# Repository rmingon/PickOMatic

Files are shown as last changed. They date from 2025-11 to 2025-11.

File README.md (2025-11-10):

# PickOMatic Motion Controller

Custom motion-control PCB for the PickOMatic pick-and-place toolchain. The board centers on an ATmega2560 (16 MHz) and exposes everything needed to drive the mechanics of a multi-head component placer: coordinated stepper motion, pneumatic handling, lighting, endstop monitoring, and USB connectivity for streaming G-code.

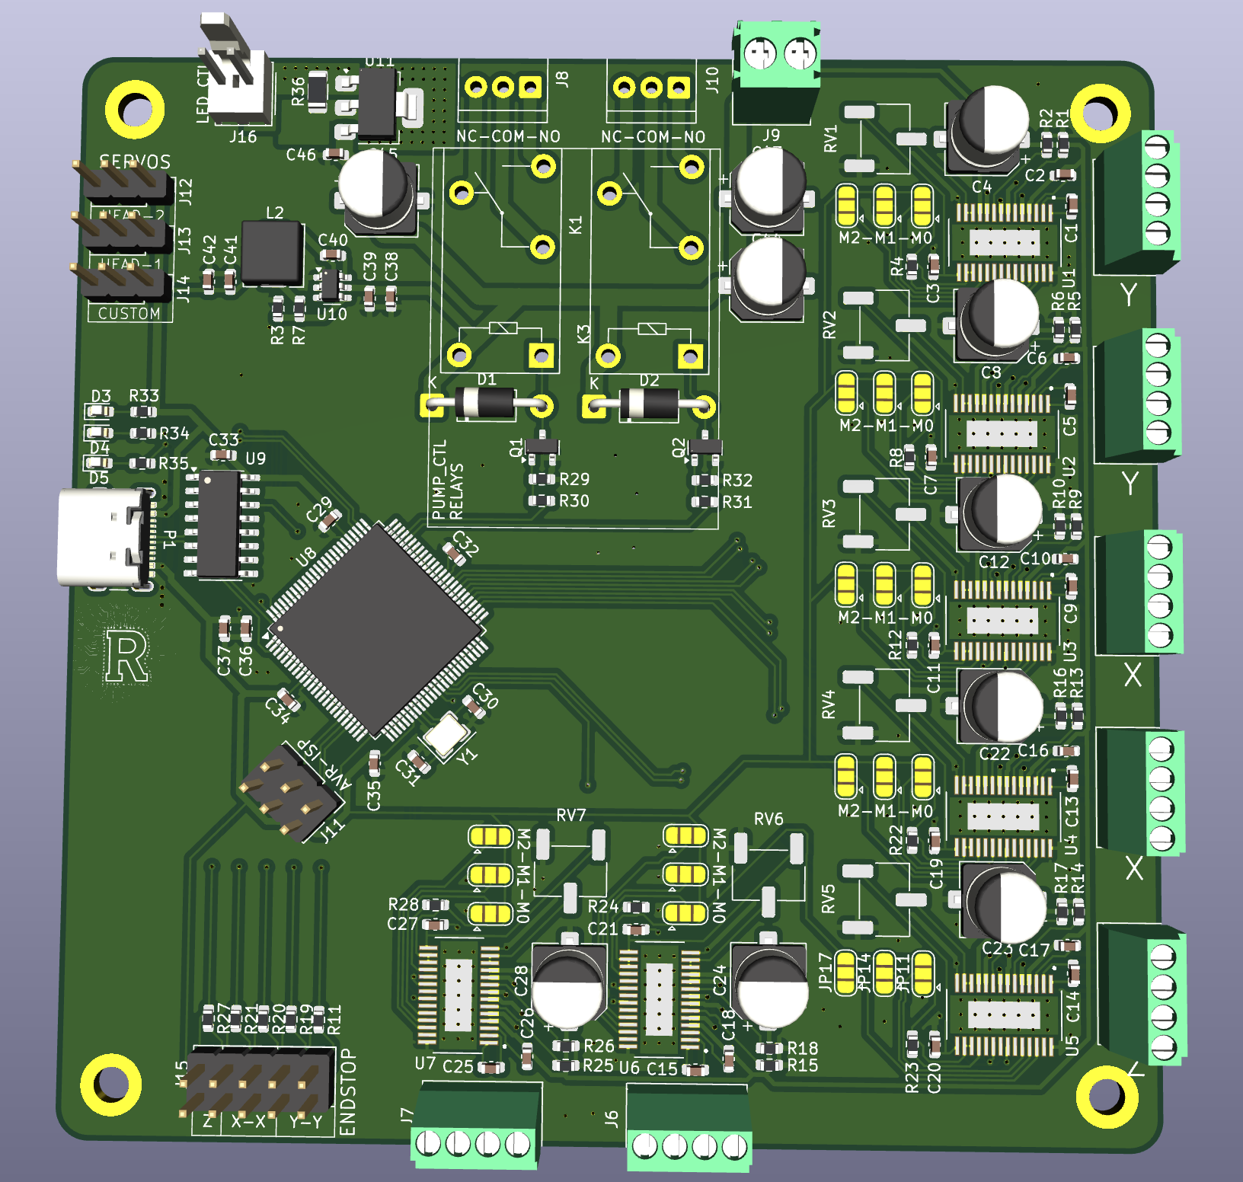
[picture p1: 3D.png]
3d


## Repository Layout

- `hardware/` – KiCad 8 project: schematic, PCB, fabrication outputs, and backups.
- `schematic.png` / `pcb.png` / `3D.png` – quick previews of the current design.

Open the KiCad project (`hardware/hardware.kicad_pro`) to inspect or modify the schematic/PCB.

## Hardware Highlights

| Function | Implementation |
| --- | --- |
| MCU | ATmega2560 @ 16 MHz with a full 5 V I/O bank exposed for motion, sensors, and auxiliary loads. |
| Programming | Standard 6-pin AVR-ISP header for bootloader bring-up, plus an onboard CH340C USB-UART for firmware uploads and runtime G-code/telemetry.  |
| Axis control | Five primary stepper channels (2×X, 2×Y, 1×Z) plus two auxiliary stepper channels dedicated to the dual picker heads. |
| Vertical compliance | Three hobby-servo outputs cooperate with the Z axis so each picker head can adjust nozzle height independently (fine pitch vs bulk parts). |
| Pneumatics & lighting | High-side driver for the vacuum/air pump and relay output for the inspection light that assists the vision camera. |
| Endstops | Five limit-switch inputs routed to PCINT lines so firmware can react immediately to any axis stop without polling latency. |

## Connectors & Loads

- **Power** – The digital domain remains at 5 V; provide the motor/lighting voltages required by your external drivers (consult the schematic to confirm connector pinouts and allowable current).
- **Steppers** – Eight pairs of STEP/DIR outputs let you interface with typical plug-in drivers (A4988, DRV8825, TMC series). Wire the two X and two Y channels to the corresponding gantry motors so firmware can keep them phase-aligned.
- **Servos** – Three 3-pin headers (signal/5 V/GND) drive standard RC servos for nozzle tilt or compliance adjustments.
- **Vacuum & light** – The pump driver is sized for continuous duty vacuum pumps; the relay contact can switch the illumination supply for the fiducial/alignment camera.
- **Endstops** – Use normally-closed switches whenever possible; the PCINT implementation catches interruptions even while the MCU is servicing other tasks.

Refer to `hardware.kicad_sch` for exact connector references, fuse ratings, and any net labels that tie into your firmware pin map.

## Getting Started

1. **Inspect the PCB** – Open the KiCad design and verify clearances, mounting, and connector orientation against your mechanical assembly.
2. **Assemble & power** – Populate the MCU, CH340C, power regulators, and the motion-control connectors. Bring up the board on a bench supply; check that 5 V and any motor rails stay within tolerance under load.
3. **Flash the bootloader** – Use an AVR ISP (e.g., USBasp, Atmel-ICE) on the 6-pin header:

   ```bash
   avrdude -c usbasp -p m2560 -U flash:w:optiboot_atmega2560.hex
   ```

4. **Deploy firmware** – Upload your motion firmware (Marlin, grbl-Mega, custom G-code interpreter) over the CH340C virtual COM port, typically at 115200 baud.
5. **Verify I/O** – Exercise each stepper, servo, and pneumatic output with low-current loads before connecting the actual actuators. Confirm that every endstop triggers in firmware by manually toggling the switches.
6. **Integrate with the PickOMatic toolchain** – Point your host software (Python scripts, OpenPnP, etc.) at the CH340C serial port and stream G-code or custom motion commands.

## Firmware Notes

- **Stepper pairing** – Configure your firmware so the twin X and Y motors share motion planners but can be trammed independently (use dual endstops or sensorless homing if supported).
- **PCINT handling** – Enable pin-change interrupts for the five limit inputs to guarantee hard-stop reactions regardless of motion planner load.
- **Auxiliary steppers** – Treat the dual picker-head steppers as independent “U” and “V” axes or bind them to tool-change macros to orient the nozzles before pick/place moves.
- **Servo timing** – The ATmega2560 has enough timers to dedicate 50 Hz PWM to the three servos; ensure your firmware does not double-book those timers for other peripherals.
- **Pneumatics & lighting** – Map the pump MOSFET and light relay pins to M-code handlers (e.g., `M8/M9` for vacuum, `M42` for light) so pick/place scripts can toggle them inline.

## ATmega2560 Pin Map

Pad numbers reference the TQFP-100 package used on this board. All mappings come directly from `hardware/hardware.kicad_pcb`.

### Stepper channels

| Channel | STEP pin / pad / net | DIR pin / pad / net | Suggested use |
| --- | --- | --- | --- |
| 1 | PC6 · pin 59 · `STEP_1` | PC7 · pin 60 · `DIR_1` | X gantry, left motor  |
| 2 | PC4 · pin 57 · `STEP_2` | PC5 · pin 58 · `DIR_2` | X gantry, right motor |
| 3 | PC2 · pin 55 · `STEP_3` | PC3 · pin 56 · `DIR_3` | Y gantry, front motor |
| 4 | PC0 · pin 53 · `STEP_4` | PC1 · pin 54 · `DIR_4` | Y gantry, rear motor  |
| 5 | PL5 · pin 40 · `STEP_5` | PL6 · pin 41 · `DIR_5` | Z axis lift |
| 6 | PL3 · pin 38 · `STEP_6` | PL4 · pin 39 · `DIR_6` | Picker A rotation |
| 7 | PL1 · pin 36 · `STEP_7` | PL2 · pin 37 · `DIR_7` | Picker B rotation |

> Firmware can reassign channel roles, but keeping 1–4 for the paired XY screws and 5–7 for the vertical/picker actuators matches the board routing and driver placement.

### Pneumatics, lighting & servos

| Function | Port / pad | Net | Notes |
| --- | --- | --- | --- |
| Vacuum / air pump relay | PA7 · pin 71 | `RELAY_1` | Drives MOSFET + relay combo for the pump manifold. |
| Vision light relay | PA6 · pin 72 | `RELAY_2` | Toggles the inspection/camera light. |
| Servo 1 (picker A tilt) | PE5 · pin 7  | `SERVO_1` | Standard 5 V RC servo header. |
| Servo 2 (picker B tilt) | PE4 · pin 6  | `SERVO_2` | Standard 5 V RC servo header. |
| Servo 3 (shared Z assist) | PE3 · pin 5  | `SERVO_3` | Use for nozzle height trim or feeder kicker. |
| Status LED | PA1 · pin 77 | `LED1` | Tie to firmware heartbeat. |
| Power LED | PA0 · pin 78 | `LED2` | Indicates logic rail alive. |

### End-stop inputs (PCINT capable)

| Input | Port / pad | Net |
| --- | --- | --- |
| Limit 1 | PJ0 · pin 63 | `END_STOP_1` |
| Limit 2 | PJ1 · pin 64 | `END_STOP_2` |
| Limit 3 | PJ2 · pin 65 | `END_STOP_3` |
| Limit 4 | PJ3 · pin 66 | `END_STOP_4` |
| Limit 5 | PJ4 · pin 67 | `END_STOP_5` |

All five pins sit on the `PCINT` bank, so configure them as pin-change interrupts for immediate homing stops.

### Communications & programming

| Interface | Port(s) / pad(s) | Net(s) | Purpose |
| --- | --- | --- | --- |
| USB-UART (CH340C) | PE0 pin 2 / PE1 pin 3 | `RX`, `TX` | Primary G-code link and bootloader uploads. |
| Aux UART1 | PD2 pin 45 / PD3 pin 46 | `RX1`, `TX1` | Spare serial for vision controller or toolchanger. |
| I²C / TWI | PD0 pin 43 / PD1 pin 44 | `SCL`, `SDA` | Plug sensors (pressure, temperature, fiducial LEDs). |
| AVR-ISP / SPI | PB1 pin 20 / PB2 pin 21 / PB3 pin 22 + RESET pin 30 | `SCK`, `MOSI`, `MISO`, `RST` | 6-pin ISP header for bootloader + in-system debugging. |

### Power, clock & reference

- VCC pins (10, 31, 61, 80, 100) tie to `+5V`; GND pins (11, 32, 62, 81, 99) tie to the main ground plane.
- `XTAL1`/`XTAL2` (pads 34/33) connect to the 16 MHz crystal network.
- `AVCC` (pad 100) shares the 5 V rail; add filtering if you extend the analog front-end.
- `AREF` (pad 98) is left uncommitted—strap it to 5 V through 100 nF if you enable analog conversions.

### Spare I/O for future features

PE2, PE6, PE7, PB0, PA2–PA5, PJ5–PJ7, PG0–PG4, PH0–PH7, and the full PF/PK analog banks are presently unassigned. They are broken out on the MCU but not routed elsewhere, so you can bodge-wire or respin the PCB for feeders, cameras, or sensor arrays without touching the core motion stack.

## Bring-Up Checklist

- Continuity-tested all power rails, especially between USB 5 V and main supply.
- Verified correct orientation of CH340C, crystal, and mini-USB connector.
- Checked that every driver enable pin defaults low (disabled) on reset.
- Confirmed pull-ups on endstop inputs so open switches read as “safe”.
- Logged baseline current draw of the pump and lighting relay to size fuses properly.

## License

This hardware is released under the **CERN Open Hardware Licence v2 (Strongly Reciprocal)**. The complete license text is provided in `LICENSE`; keep it with any derivatives or redistributions and review <https://ohwr.org/project/cernohl/wikis/Documents/CERN-OHL-version-2> for updates.

---

Questions, improvements, or bring-up notes are welcome—open an issue or document your findings so the community can build better pick-and-place rigs together.

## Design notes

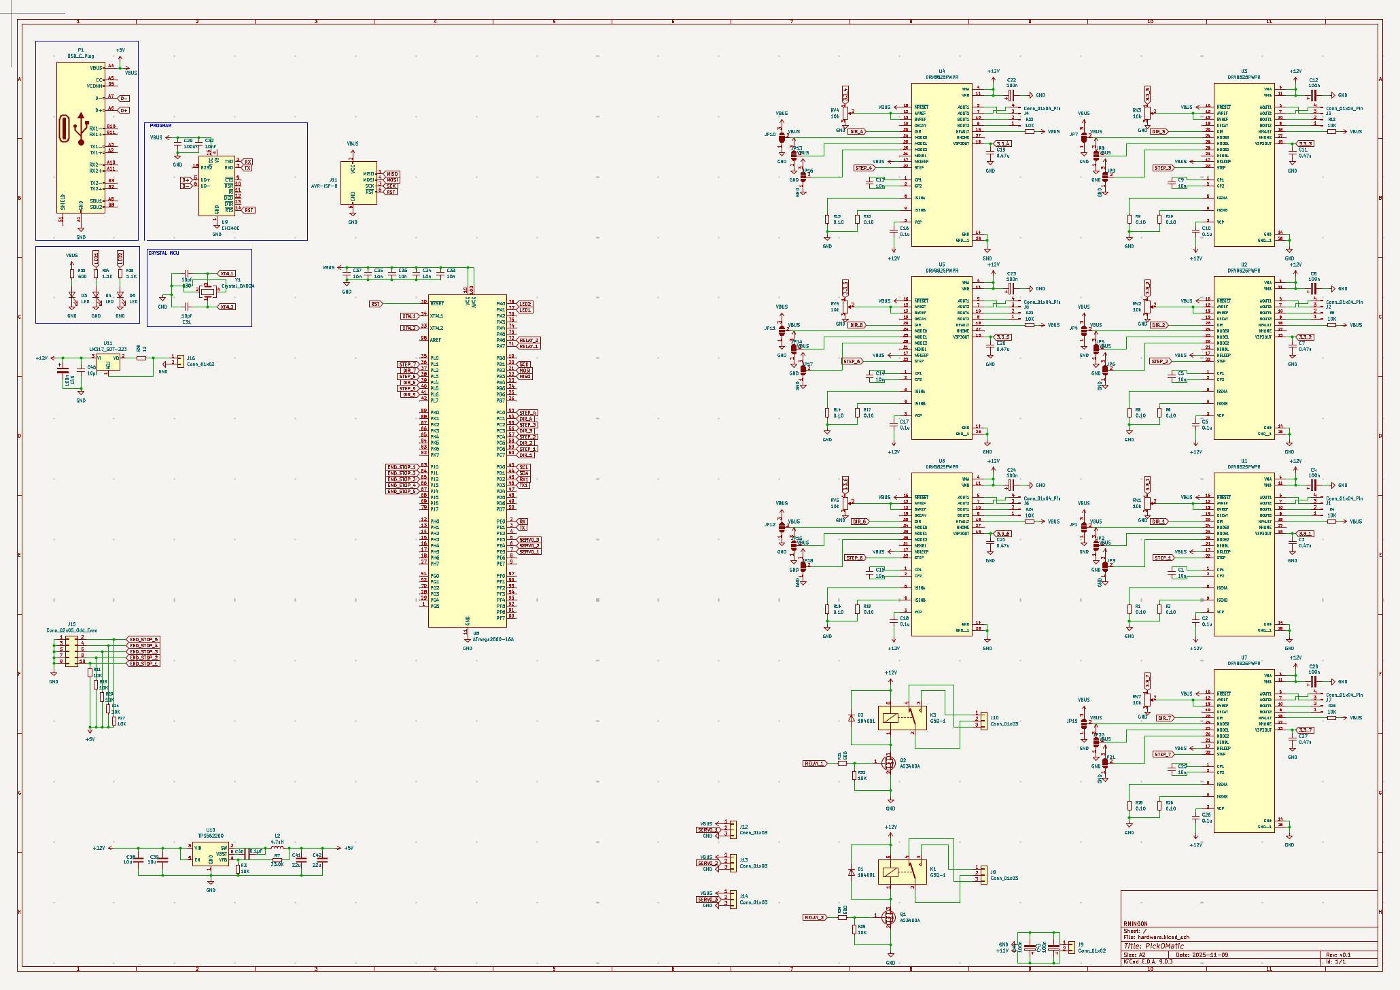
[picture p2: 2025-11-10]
schematic.png

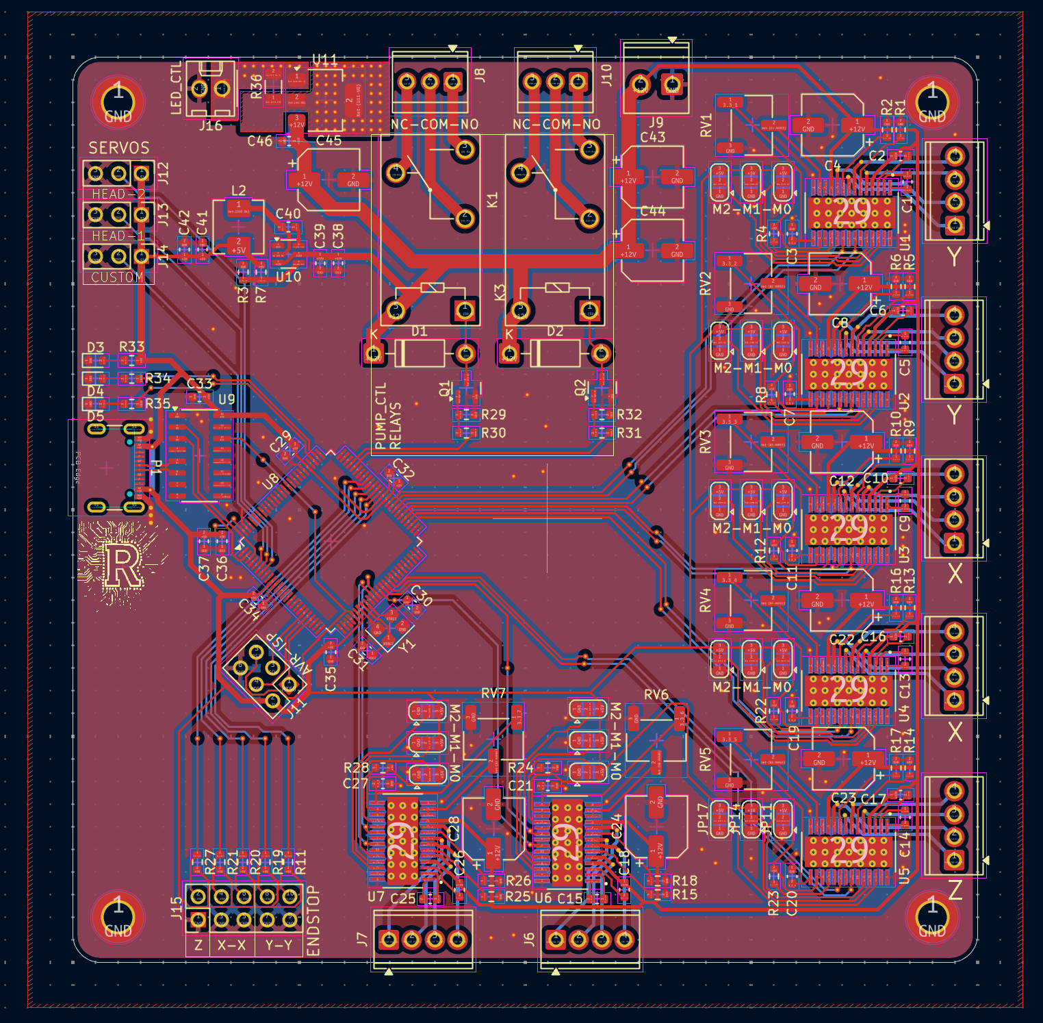
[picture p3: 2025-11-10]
pcb.png

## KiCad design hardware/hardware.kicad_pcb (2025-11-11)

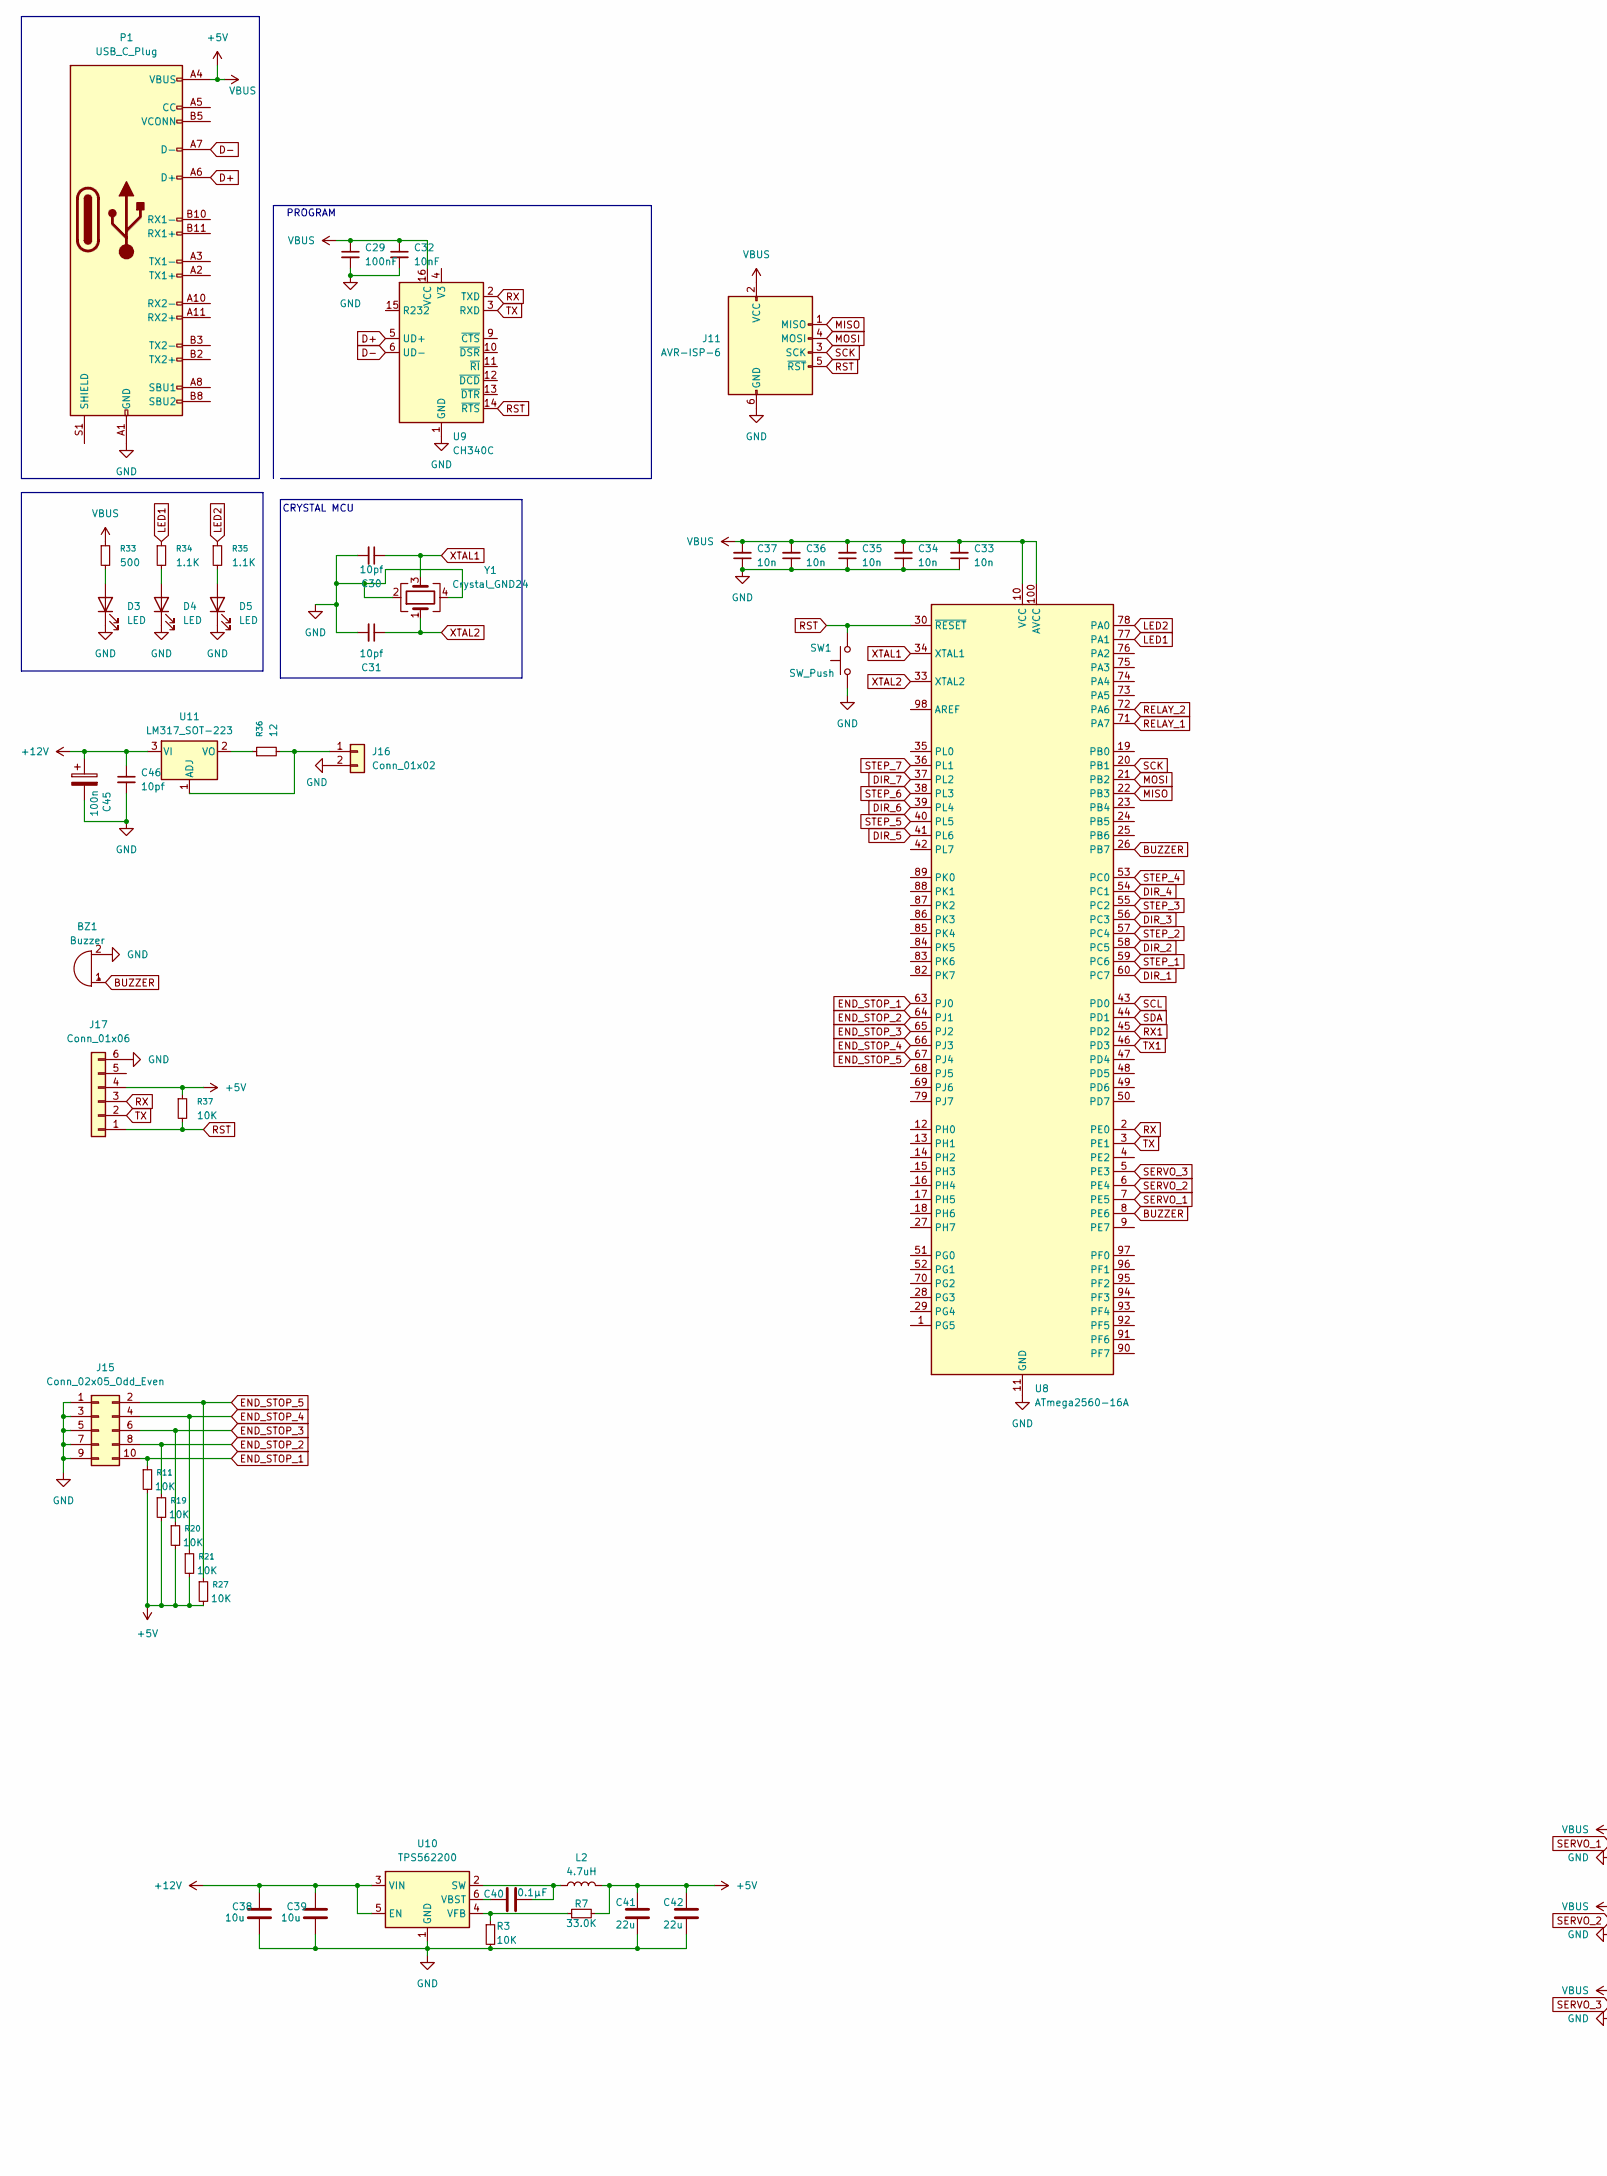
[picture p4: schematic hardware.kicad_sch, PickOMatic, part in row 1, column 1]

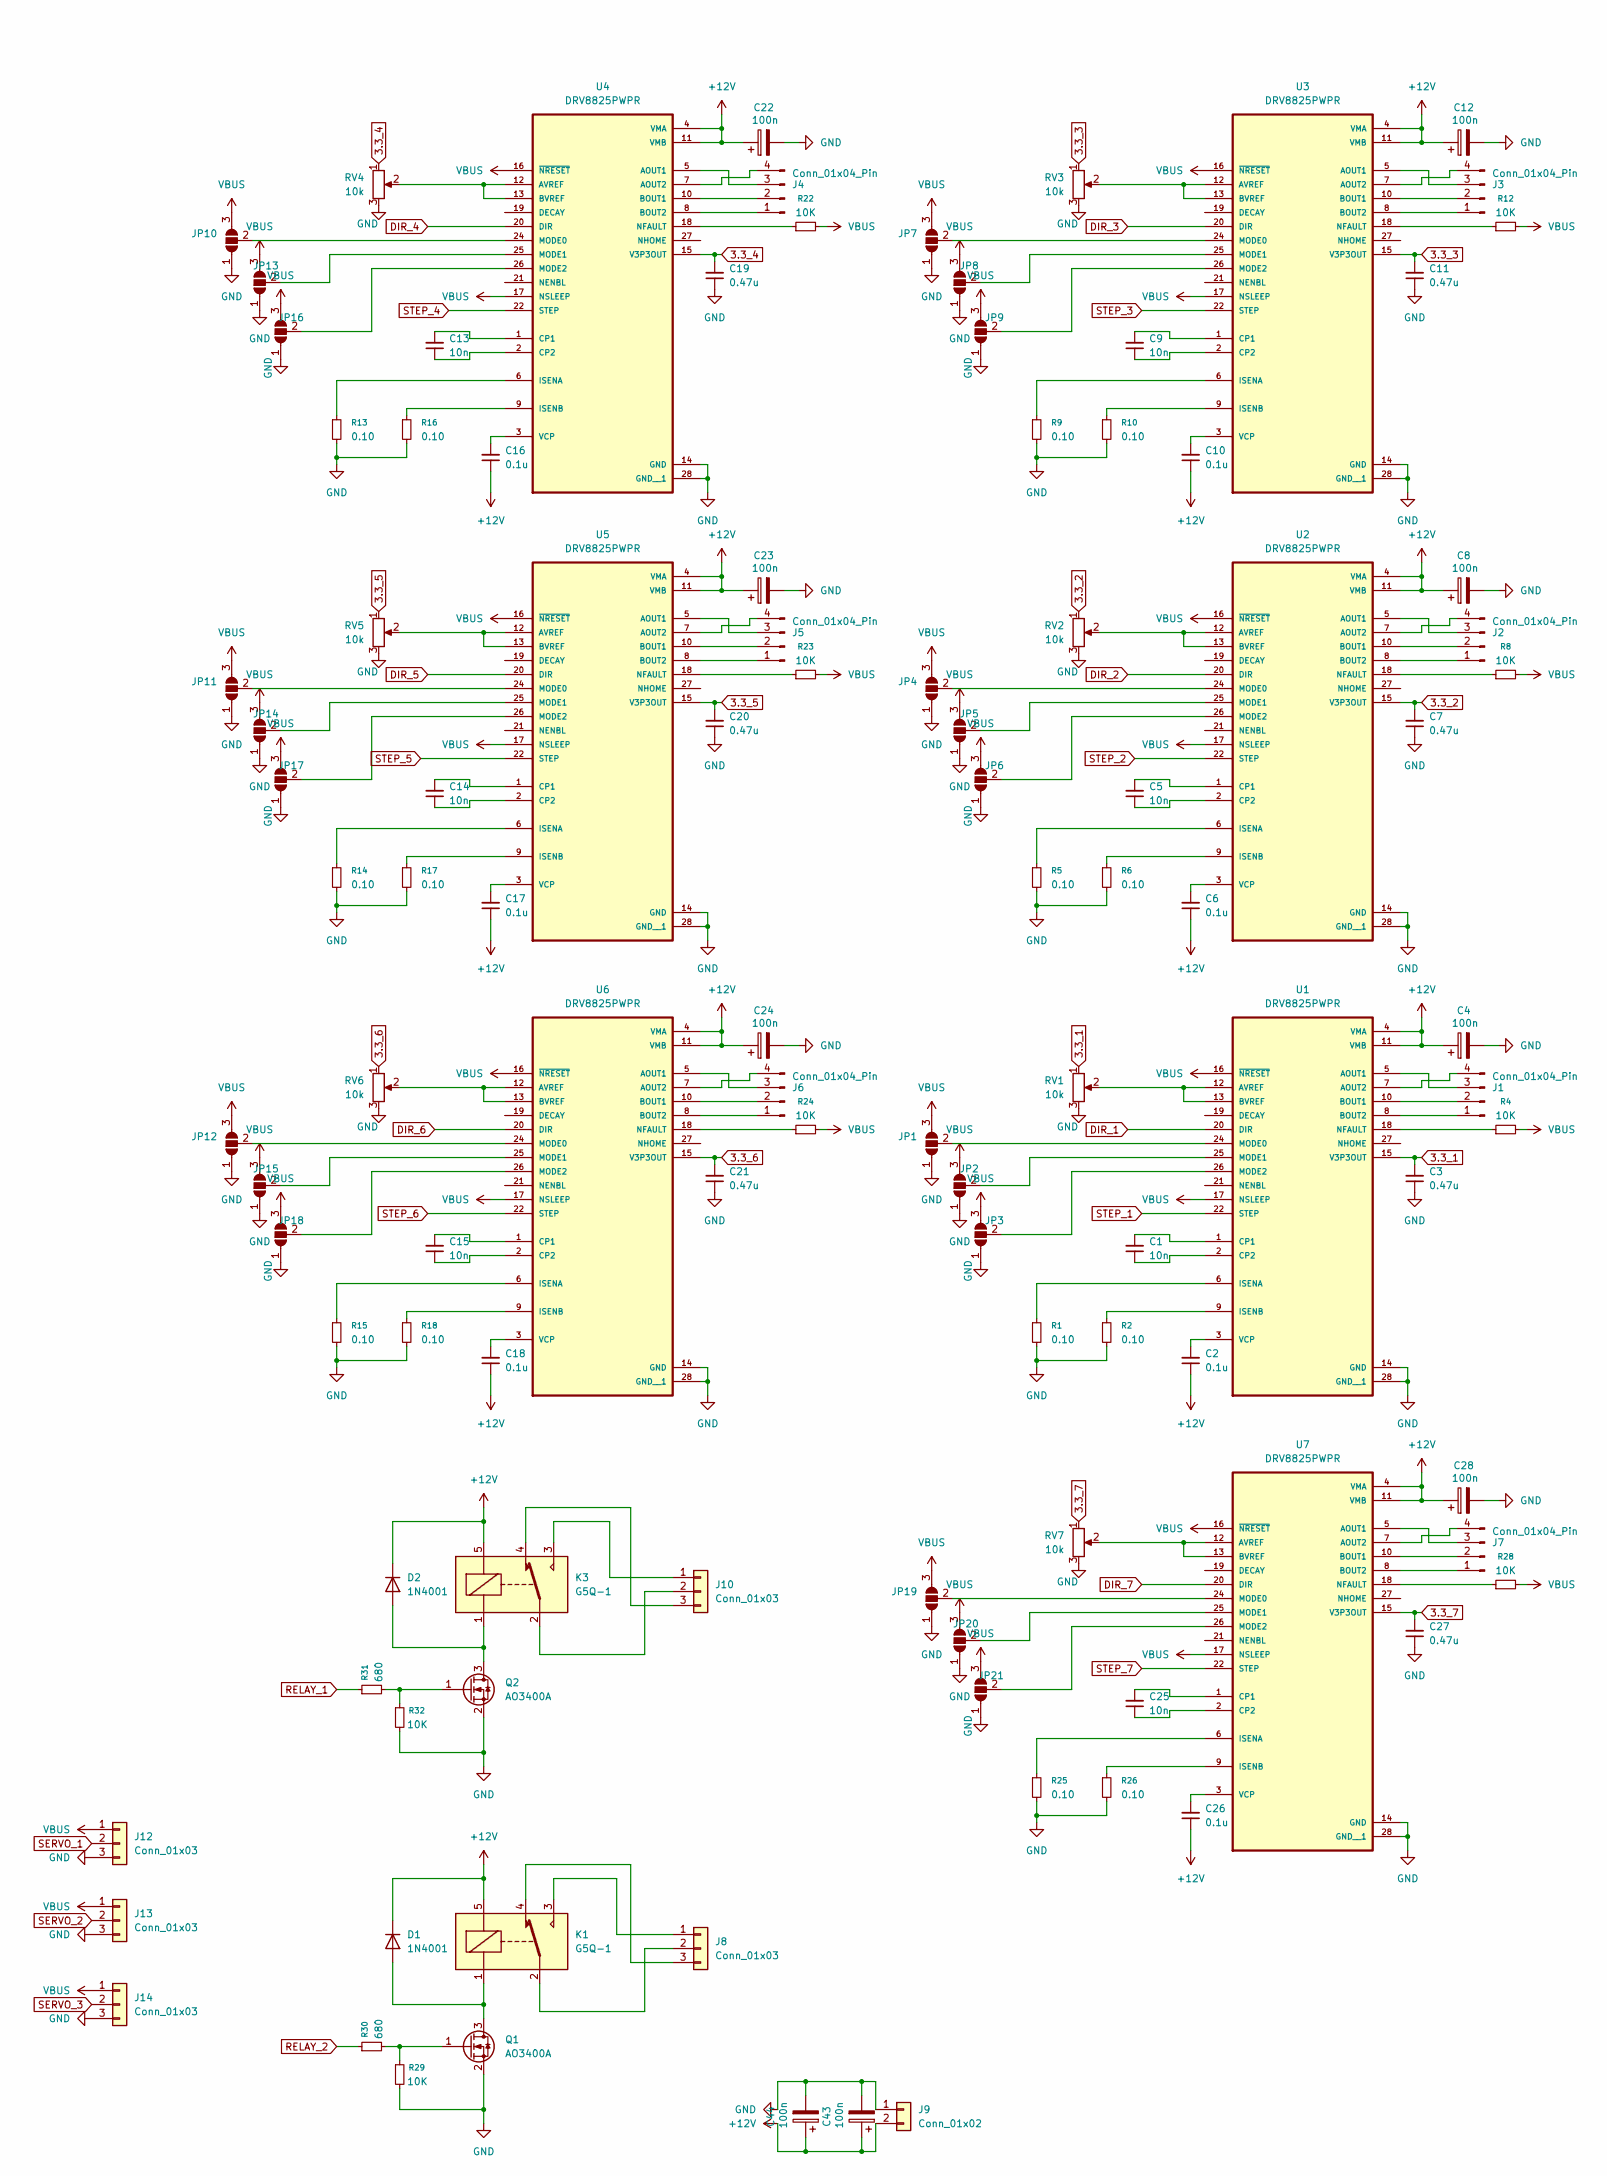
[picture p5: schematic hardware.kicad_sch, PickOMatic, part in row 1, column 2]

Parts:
BZ1: Buzzer; Buzzer_TDK_PS1240P02BT_D12.2mm_H6.5mm
C1, C5, C9, C13, C14, C15, C25, C33, C34, C35, C36, C37: 10n; C_0603_1608Metric
C2, C6, C10, C16, C17, C18, C26: 0.1u; C_0603_1608Metric
C3, C7, C11, C19, C20, C21, C27: 0.47u; C_0603_1608Metric
C4, C8, C12, C22, C23, C24, C28, C43, C44, C45: 100n; CP_Elec_6.3x5.7
C29: 100nF; C_0603_1608Metric
C30, C31, C46: 10pf; C_0603_1608Metric; LCSC C106245
C32: 10nF; C_0603_1608Metric
C38, C39: 10u; C_0603_1608Metric; LCSC C1691
C40: 0.1µF; C_0603_1608Metric; LCSC C6119867
C41, C42: 22u; C_0603_1608Metric; LCSC C6119867
D1, D2: 1N4001; D_DO-41_SOD81_P10.16mm_Horizontal
D3, D4, D5: LED; LED_0603_1608Metric
J1, J2, J3, J4, J5, J6, J7: Conn_01x04_Pin; TerminalBlock_Phoenix_MPT-0,5-4-2.54_1x04_P2.54mm_Horizontal
J8, J10: Conn_01x03; TerminalBlock_TE_282834-3_1x03_P2.54mm_Horizontal
J9: Conn_01x02; TerminalBlock_Phoenix_PT-1,5-2-3.5-H_1x02_P3.50mm_Horizontal
J11: AVR-ISP-6; PinHeader_2x03_P2.54mm_Vertical
J12, J13, J14: Conn_01x03; PinHeader_1x03_P2.54mm_Vertical
J15: Conn_02x05_Odd_Even; PinHeader_2x05_P2.54mm_Vertical
J16: Conn_01x02; Molex_KK-254_AE-6410-02A_1x02_P2.54mm_Vertical
J17: Conn_01x06; PinHeader_1x06_P2.54mm_Vertical
JP1, JP2, JP3, JP4, JP5, JP6, JP7, JP8, JP9, JP10, JP11, JP12, JP13, JP14, JP15, JP16, JP17, JP18, JP19, JP20, JP21: SolderJumper_3_Open; SolderJumper-3_P1.3mm_Open_RoundedPad1.0x1.5mm
K1, K3: G5Q-1; Relay_SPDT_Omron-G5Q-1
L2: 4.7uH; L_Chilisin_BMRA00050520; LCSC C3002619
P1: USB_C_Plug; USB_C_Receptacle_GCT_USB4105-xx-A_16P_TopMnt_Horizontal
Q1, Q2: AO3400A; SOT-23
R1, R2, R5, R6, R9, R10, R13, R14, R15, R16, R17, R18, R25, R26: 0.10; R_0603_1608Metric
R3: 10K; R_0603_1608Metric; LCSC C25804
R4, R8, R11, R12, R19, R20, R21, R22, R23, R24, R27, R28, R29, R32, R37: 10K; R_0603_1608Metric
R7: 33.0K; R_0603_1608Metric; LCSC C4216
R30, R31: 680; R_0603_1608Metric
R33: 500; R_0603_1608Metric
R34, R35: 1.1K; R_0603_1608Metric
R36: 12; R_1206_3216Metric
RV1, RV2, RV3, RV4, RV5, RV6, RV7: 10k; Potentiometer_Bourns_3269W_Vertical
SW1: SW_Push; SW_SPST_CK_RS282G05A3
U1, U2, U3, U4, U5, U6, U7: DRV8825PWPR; IC_TPS61196PWPRQ1
U8: ATmega2560-16A; TQFP-100_14x14mm_P0.5mm
U9: CH340C; SOIC-16_3.9x9.9mm_P1.27mm
U10: TPS562200; SOT-23-6; LCSC C49757
U11: LM317_SOT-223; SOT-223-3_TabPin2
Y1: Crystal_GND24; Crystal_SMD_3225-4Pin_3.2x2.5mm

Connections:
3.3_1: C3.2, RV1.1, U1.15 (V3P3OUT)
3.3_2: C7.2, RV2.1, U2.15 (V3P3OUT)
3.3_3: C11.2, RV3.1, U3.15 (V3P3OUT)
3.3_4: C19.2, RV4.1, U4.15 (V3P3OUT)
3.3_5: C20.2, RV5.1, U5.15 (V3P3OUT)
3.3_6: C21.2, RV6.1, U6.15 (V3P3OUT)
3.3_7: C27.2, RV7.1, U7.15 (V3P3OUT)
+5V: C29.1, C32.1, C33.2, C34.2, C35.2, C36.2, C37.2, C41.1, C42.1, J11.2 (VCC), J12.1, J13.1, J14.1, J17.4, JP1.3 (B), JP2.3 (B), JP3.3 (B), JP4.3 (B), JP5.3 (B), JP6.3 (B), JP7.3 (B), JP8.3 (B), JP9.3 (B), JP10.3 (B), JP11.3 (B), JP12.3 (B), JP13.3 (B), JP14.3 (B), JP15.3 (B), JP16.3 (B), JP17.3 (B), JP18.3 (B), JP19.3 (B), JP20.3 (B), JP21.3 (B), L2.2, P1.A4 (VBUS), P1.A9 (VBUS), P1.B4 (VBUS), P1.B9 (VBUS), R4.2, R7.2, R8.2, R11.2, R12.2, R19.2, R20.2, R21.2, R22.2, R23.2, R24.2, R27.2, R28.2, R33.1, R37.1, U1.16 (~NRESET), U1.17 (NSLEEP), U2.16 (~NRESET), U2.17 (NSLEEP), U3.16 (~NRESET), U3.17 (NSLEEP), U4.16 (~NRESET), U4.17 (NSLEEP), U5.16 (~NRESET), U5.17 (NSLEEP), U6.16 (~NRESET), U6.17 (NSLEEP), U7.16 (~NRESET), U7.17 (NSLEEP), U8.10 (VCC), U8.31 (VCC), U8.61 (VCC), U8.80 (VCC), U8.100 (AVCC), U9.16 (VCC)
+12V: C2.1, C4.1, C6.1, C8.1, C10.1, C12.1, C16.1, C17.1, C18.1, C22.1, C23.1, C24.1, C26.1, C28.1, C38.1, C39.1, C43.1, C44.1, C45.1, C46.1, D1.1 (K), D2.1 (K), J9.2, K1.5, K3.5, U1.4 (VMA), U1.11 (VMB), U2.4 (VMA), U2.11 (VMB), U3.4 (VMA), U3.11 (VMB), U4.4 (VMA), U4.11 (VMB), U5.4 (VMA), U5.11 (VMB), U6.4 (VMA), U6.11 (VMB), U7.4 (VMA), U7.11 (VMB), U10.3 (VIN), U10.5 (EN), U11.3 (VI)
BUZZER: BZ1.1 (+), U8.8 (PE6), U8.26 (PB7)
D+: P1.A6 (D+), U9.5 (UD+)
D-: P1.A7 (D-), U9.6 (UD-)
DIR_1: U1.20 (DIR), U8.60 (PC7)
DIR_2: U2.20 (DIR), U8.58 (PC5)
DIR_3: U3.20 (DIR), U8.56 (PC3)
DIR_4: U4.20 (DIR), U8.54 (PC1)
DIR_5: U5.20 (DIR), U8.41 (PL6)
DIR_6: U6.20 (DIR), U8.39 (PL4)
DIR_7: U7.20 (DIR), U8.37 (PL2)
END_STOP_1: J15.10, R11.1, U8.63 (PJ0)
END_STOP_2: J15.8, R19.1, U8.64 (PJ1)
END_STOP_3: J15.6, R20.1, U8.65 (PJ2)
END_STOP_4: J15.4, R21.1, U8.66 (PJ3)
END_STOP_5: J15.2, R27.1, U8.67 (PJ4)
GND: BZ1.2 (-), C3.1, C4.2, C7.1, C8.2, C11.1, C12.2, C19.1, C20.1, C21.1, C22.2, C23.2, C24.2, C27.1, C28.2, C29.2, C30.2, C31.2, C32.2, C33.1, C34.1, C35.1, C36.1, C37.1, C38.2, C39.2, C41.2, C42.2, C43.2, C44.2, C45.2, C46.2, D3.1 (K), D4.1 (K), D5.1 (K), J9.1, J11.6 (GND), J12.3, J13.3, J14.3, J15.1, J15.3, J15.5, J15.7, J15.9, J16.2, J17.6, JP1.1 (A), JP2.1 (A), JP3.1 (A), JP4.1 (A), JP5.1 (A), JP6.1 (A), JP7.1 (A), JP8.1 (A), JP9.1 (A), JP10.1 (A), JP11.1 (A), JP12.1 (A), JP13.1 (A), JP14.1 (A), JP15.1 (A), JP16.1 (A), JP17.1 (A), JP18.1 (A), JP19.1 (A), JP20.1 (A), JP21.1 (A), P1.A1 (GND), P1.A12 (GND), P1.B1 (GND), P1.B12 (GND), Q1.2 (S), Q2.2 (S), R1.2, R2.2, R3.2, R5.2, R6.2, R9.2, R10.2, R13.2, R14.2, R15.2, R16.2, R17.2, R18.2, R25.2, R26.2, R29.2, R32.2, RV1.3, RV2.3, RV3.3, RV4.3, RV5.3, RV6.3, RV7.3, SW1.1, U1.14 (GND), U1.28 (GND__1), U2.14 (GND), U2.28 (GND__1), U3.14 (GND), U3.28 (GND__1), U4.14 (GND), U4.28 (GND__1), U5.14 (GND), U5.28 (GND__1), U6.14 (GND), U6.28 (GND__1), U7.14 (GND), U7.28 (GND__1), U8.11 (GND), U8.32 (GND), U8.62 (GND), U8.81 (GND), U8.99 (GND), U9.1 (GND), U10.1 (GND), Y1.2, Y1.4; also elsewhere on the board
LED1: R34.1, U8.77 (PA1)
LED2: R35.1, U8.78 (PA0)
MISO: J11.1 (MISO), U8.22 (PB3)
MOSI: J11.4 (MOSI), U8.21 (PB2)
unnamed: D1.2 (A), K1.1, Q1.3 (D)
unnamed: D2.2 (A), K3.1, Q2.3 (D)
unnamed: D3.2 (A), R33.2
unnamed: D4.2 (A), R34.2
unnamed: D5.2 (A), R35.2
unnamed: J1.1, U1.8 (BOUT2)
unnamed: J1.2, U1.10 (BOUT1)
unnamed: J1.3, U1.5 (AOUT1)
unnamed: J1.4, U1.7 (AOUT2)
unnamed: J2.1, U2.8 (BOUT2)
unnamed: J2.2, U2.10 (BOUT1)
unnamed: J2.3, U2.5 (AOUT1)
unnamed: J2.4, U2.7 (AOUT2)
unnamed: J3.1, U3.8 (BOUT2)
unnamed: J3.2, U3.10 (BOUT1)
unnamed: J3.3, U3.5 (AOUT1)
unnamed: J3.4, U3.7 (AOUT2)
unnamed: J4.1, U4.8 (BOUT2)
unnamed: J4.2, U4.10 (BOUT1)
unnamed: J4.3, U4.5 (AOUT1)
unnamed: J4.4, U4.7 (AOUT2)
unnamed: J5.1, U5.8 (BOUT2)
unnamed: J5.2, U5.10 (BOUT1)
unnamed: J5.3, U5.5 (AOUT1)
unnamed: J5.4, U5.7 (AOUT2)
unnamed: J6.1, U6.8 (BOUT2)
unnamed: J6.2, U6.10 (BOUT1)
unnamed: J6.3, U6.5 (AOUT1)
unnamed: J6.4, U6.7 (AOUT2)
unnamed: J7.1, U7.8 (BOUT2)
unnamed: J7.2, U7.10 (BOUT1)
unnamed: J7.3, U7.5 (AOUT1)
unnamed: J7.4, U7.7 (AOUT2)
unnamed: J8.1, K1.3
unnamed: J8.2, K1.2
unnamed: J8.3, K1.4
unnamed: J10.1, K3.3
unnamed: J10.2, K3.2
unnamed: J10.3, K3.4
unnamed: J16.1, R36.2, U11.1 (ADJ)
unnamed: JP1.2 (C), U1.24 (MODE0)
unnamed: JP2.2 (C), U1.25 (MODE1)
unnamed: JP3.2 (C), U1.26 (MODE2)
unnamed: JP4.2 (C), U2.24 (MODE0)
unnamed: JP5.2 (C), U2.25 (MODE1)
unnamed: JP6.2 (C), U2.26 (MODE2)
unnamed: JP7.2 (C), U3.24 (MODE0)
unnamed: JP8.2 (C), U3.25 (MODE1)
unnamed: JP9.2 (C), U3.26 (MODE2)
unnamed: JP10.2 (C), U4.24 (MODE0)
unnamed: JP11.2 (C), U5.24 (MODE0)
unnamed: JP12.2 (C), U6.24 (MODE0)
unnamed: JP13.2 (C), U4.25 (MODE1)
unnamed: JP14.2 (C), U5.25 (MODE1)
unnamed: JP15.2 (C), U6.25 (MODE1)
unnamed: JP16.2 (C), U4.26 (MODE2)
unnamed: JP17.2 (C), U5.26 (MODE2)
unnamed: JP18.2 (C), U6.26 (MODE2)
unnamed: JP19.2 (C), U7.24 (MODE0)
unnamed: JP20.2 (C), U7.25 (MODE1)
unnamed: JP21.2 (C), U7.26 (MODE2)
unnamed: Q1.1 (G), R29.1, R30.2
unnamed: Q2.1 (G), R31.2, R32.1
unnamed: RV1.2, U1.12 (AVREF), U1.13 (BVREF)
unnamed: C1.2, U1.1 (CP1)
unnamed: C1.1, U1.2 (CP2)
unnamed: R1.1, U1.6 (ISENA)
unnamed: R2.1, U1.9 (ISENB)
unnamed: R4.1, U1.18 (NFAULT)
unnamed: C2.2, U1.3 (VCP)
unnamed: RV2.2, U2.12 (AVREF), U2.13 (BVREF)
unnamed: C5.2, U2.1 (CP1)
unnamed: C5.1, U2.2 (CP2)
unnamed: R5.1, U2.6 (ISENA)
unnamed: R6.1, U2.9 (ISENB)
unnamed: R8.1, U2.18 (NFAULT)
unnamed: C6.2, U2.3 (VCP)
unnamed: RV3.2, U3.12 (AVREF), U3.13 (BVREF)
unnamed: C9.2, U3.1 (CP1)
unnamed: C9.1, U3.2 (CP2)
unnamed: R9.1, U3.6 (ISENA)
unnamed: R10.1, U3.9 (ISENB)
unnamed: R12.1, U3.18 (NFAULT)
unnamed: C10.2, U3.3 (VCP)
unnamed: RV4.2, U4.12 (AVREF), U4.13 (BVREF)
unnamed: C13.2, U4.1 (CP1)
unnamed: C13.1, U4.2 (CP2)
unnamed: R13.1, U4.6 (ISENA)
unnamed: R16.1, U4.9 (ISENB)
unnamed: R22.1, U4.18 (NFAULT)
unnamed: C16.2, U4.3 (VCP)
unnamed: RV5.2, U5.12 (AVREF), U5.13 (BVREF)
unnamed: C14.2, U5.1 (CP1)
unnamed: C14.1, U5.2 (CP2)
unnamed: R14.1, U5.6 (ISENA)
unnamed: R17.1, U5.9 (ISENB)
unnamed: R23.1, U5.18 (NFAULT)
unnamed: C17.2, U5.3 (VCP)
unnamed: RV6.2, U6.12 (AVREF), U6.13 (BVREF)
unnamed: C15.2, U6.1 (CP1)
unnamed: C15.1, U6.2 (CP2)
unnamed: R15.1, U6.6 (ISENA)
unnamed: R18.1, U6.9 (ISENB)
unnamed: R24.1, U6.18 (NFAULT)
unnamed: C18.2, U6.3 (VCP)
unnamed: RV7.2, U7.12 (AVREF), U7.13 (BVREF)
unnamed: C25.2, U7.1 (CP1)
unnamed: C25.1, U7.2 (CP2)
unnamed: R25.1, U7.6 (ISENA)
unnamed: R26.1, U7.9 (ISENB)
unnamed: R28.1, U7.18 (NFAULT)
unnamed: C26.2, U7.3 (VCP)
unnamed: C40.2, L2.1, U10.2 (SW)
unnamed: C40.1, U10.6 (VBST)
unnamed: R3.1, R7.1, U10.4 (VFB)
unnamed: R36.1, U11.2 (VO)
RELAY_1: R31.1, U8.71 (PA7)
RELAY_2: R30.1, U8.72 (PA6)
RST: J11.5 (~RST), J17.1, R37.2, SW1.2, U8.30 (~RESET), U9.14 (~RTS); also elsewhere on the board
RX: J17.3, U8.2 (PE0), U9.2 (TXD)
RX1: U8.45 (PD2)
SCK: J11.3 (SCK), U8.20 (PB1)
SCL: U8.43 (PD0)
SDA: U8.44 (PD1)
SERVO_1: J12.2, U8.7 (PE5)
SERVO_2: J13.2, U8.6 (PE4)
SERVO_3: J14.2, U8.5 (PE3)
STEP_1: U1.22 (STEP), U8.59 (PC6)
STEP_2: U2.22 (STEP), U8.57 (PC4)
STEP_3: U3.22 (STEP), U8.55 (PC2)
STEP_4: U4.22 (STEP), U8.53 (PC0)
STEP_5: U5.22 (STEP), U8.40 (PL5)
STEP_6: U6.22 (STEP), U8.38 (PL3)
STEP_7: U7.22 (STEP), U8.36 (PL1)
TX: J17.2, U8.3 (PE1), U9.3 (RXD)
TX1: U8.46 (PD3)
XTAL1: C30.1, U8.34 (XTAL1), Y1.3
XTAL2: C31.1, U8.33 (XTAL2), Y1.1

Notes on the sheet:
PROGRAM
CRYSTAL MCU

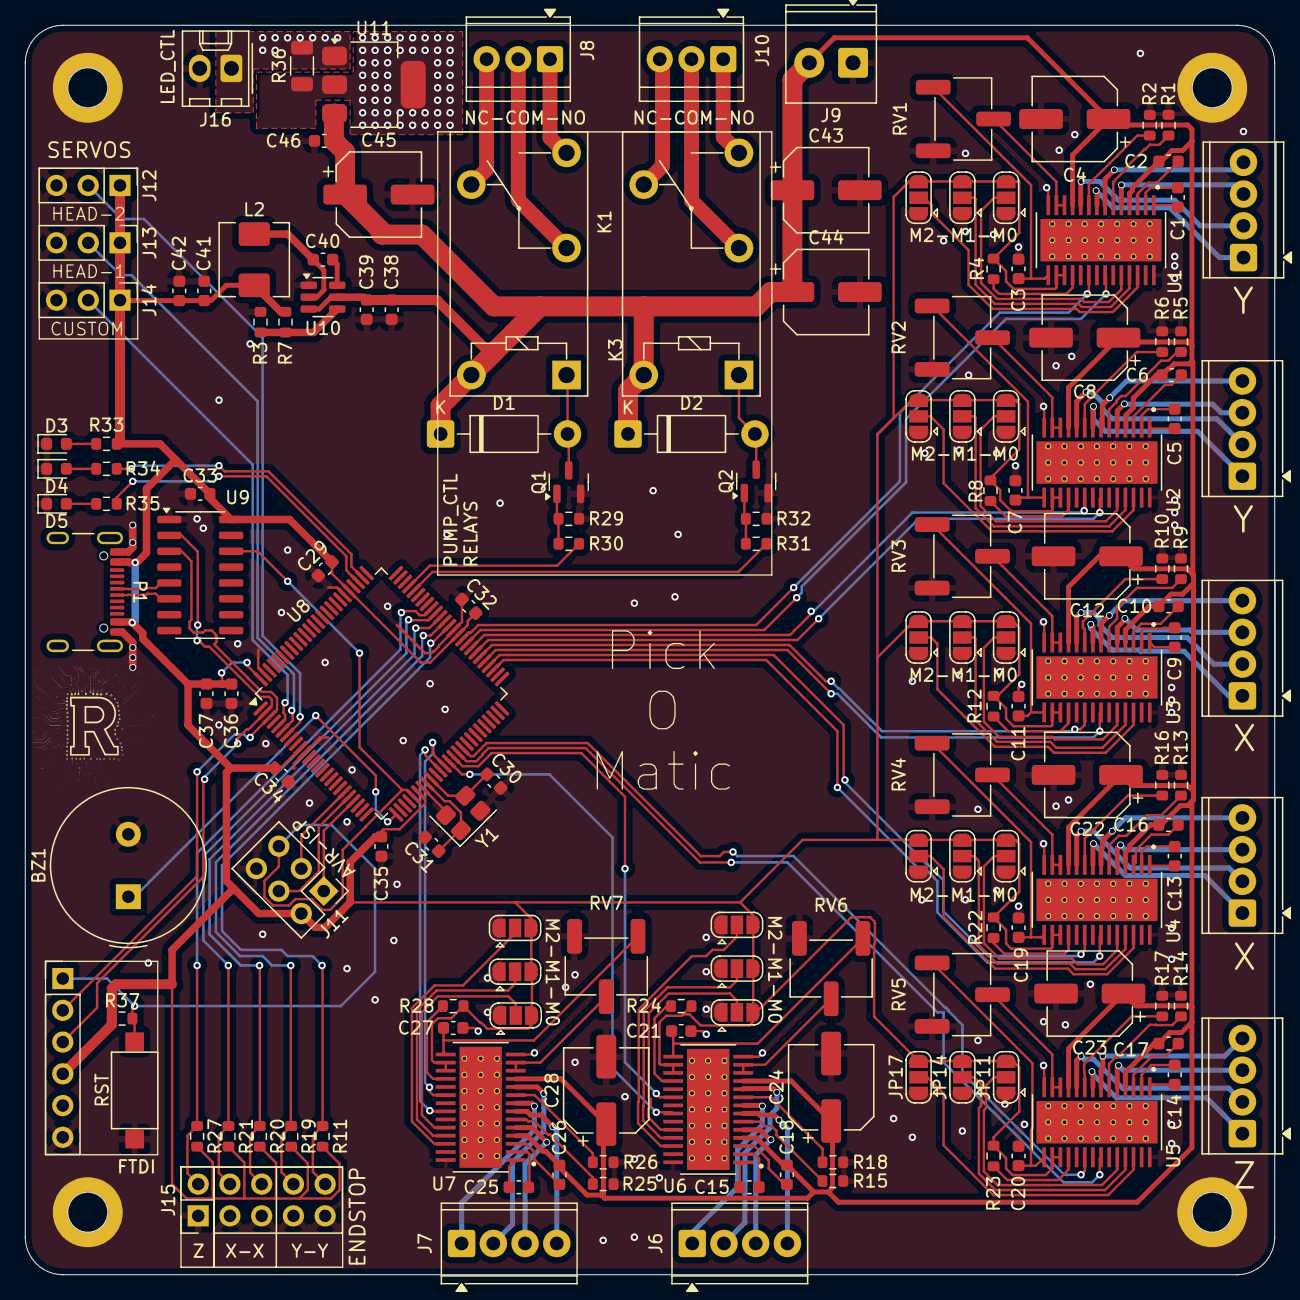
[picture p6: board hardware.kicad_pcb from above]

Board: 2 copper layers, 100.0 x 100.0 mm, 153 parts (0 on the bottom side), 163 nets.

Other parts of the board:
RST: SW_Push; SW_SPST_CK_RS282G05A3

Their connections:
GND: RST.1; also elsewhere on the board
RST: RST.2; also elsewhere on the board

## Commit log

2025-11-09 add stepper motor schematic
    [hardware.kicad_pcb, hardware.kicad_sch]
2025-11-09 add relay + mcu schematic
    [hardware.kicad_sch]
2025-11-09 add connector + uart to usb + avr isp programming schematic
    [hardware.kicad_sch]
2025-11-09 add pcb and footprints components
    [hardware.kicad_pcb, hardware.kicad_sch]
2025-11-09 placing relay + drv + edit relay footprints
    [hardware.kicad_pcb, hardware.kicad_sch]
2025-11-09 wire all drv
    [hardware.kicad_pcb, hardware.kicad_sch]
2025-11-09 finish pcb wiring
    [hardware.kicad_pcb, hardware.kicad_sch]
2025-11-09 fix relay +led wiring
    [hardware.kicad_pcb, hardware.kicad_sch]
2025-11-10 wire current regulator
    [hardware.kicad_pcb, hardware.kicad_sch]
2025-11-10 finish wiring
    [hardware.kicad_pcb]
2025-11-11 add ftdi + buzzer + rst button
    [hardware.kicad_pcb, hardware.kicad_sch]
